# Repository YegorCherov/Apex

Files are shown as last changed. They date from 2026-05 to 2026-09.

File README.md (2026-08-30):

# Apex

Sequential 4-payload dropper for FPV drones, driven by a single servo.

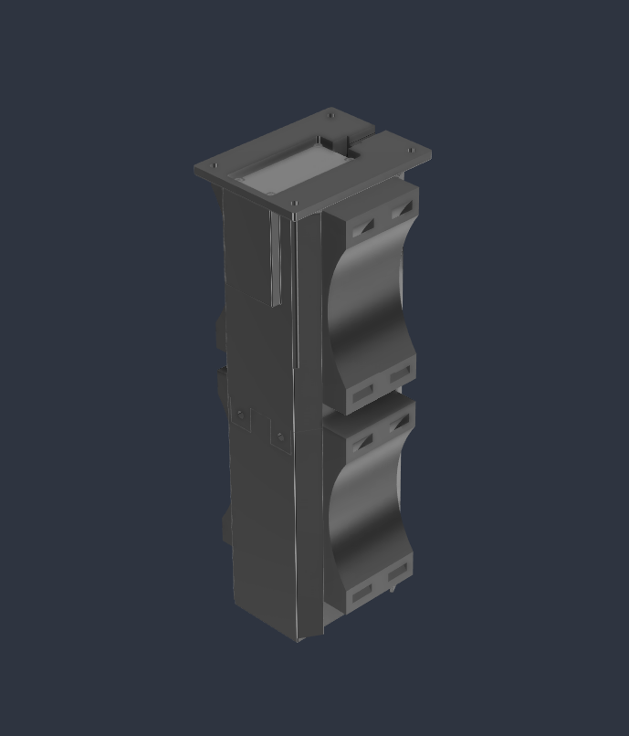
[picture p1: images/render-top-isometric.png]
Apex mounted on drone - top isometric view

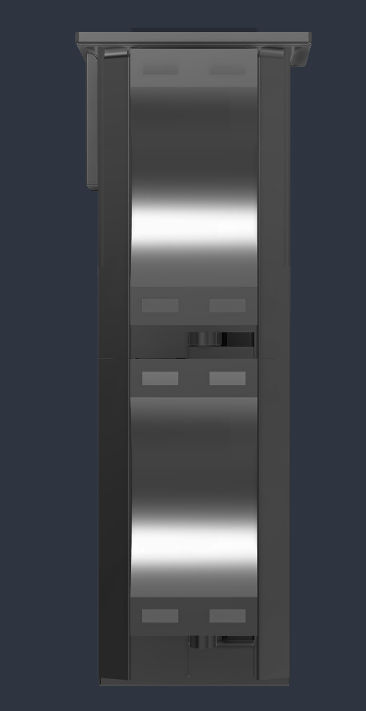
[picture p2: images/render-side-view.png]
Apex drone integration - side view with landing gear


## Overview

Apex drops up to four independent payloads at separate points in a single 180° servo sweep. There's no onboard electronics beyond the servo itself and no extra FC channels beyond the one driving it.

Payloads attach through zip ties rather than a fixed-geometry bay, so the same hardware handles a wide range of payload shapes and sizes without reprinting.

**Demos**

https://github.com/user-attachments/assets/e3766b08-4272-4210-bcb9-dfcf5e273cf3

V1, SG90 servo, split arm heights.

https://github.com/user-attachments/assets/bb46a15b-bc07-45ec-ad2f-8966f5d29cbe

V2, SG90 servo, unified arm set. The current release (V3) keeps V2's geometry but replaces the servo, see [Version History](#version-history).

## Features

- 4 sequential drops from a single 180° servo sweep
- Single MG996R servo, no added FC channels
- Zip tie payload mounting, works with S and M holders (8 or 4 payload capacity respectively)
- No springs, detents, or secondary latching, the Geneva mechanism holds position on its own
- Base plate bolts to a standard 10" frame pattern, adaptable to other frames in CAD

## Why not an existing design

| Approach | Limitation |
|---|---|
| Single-payload flap/pin release | One drop per flight |
| One servo per payload | Burns FC channels, adds weight and wiring |
| Revolver-style bay | Bay radius is fixed at print time, payload size can't change without a reprint |

Apex targets all of these at once: one servo, multiple sequential drops, and payload geometry that isn't baked into the print.

## How it works

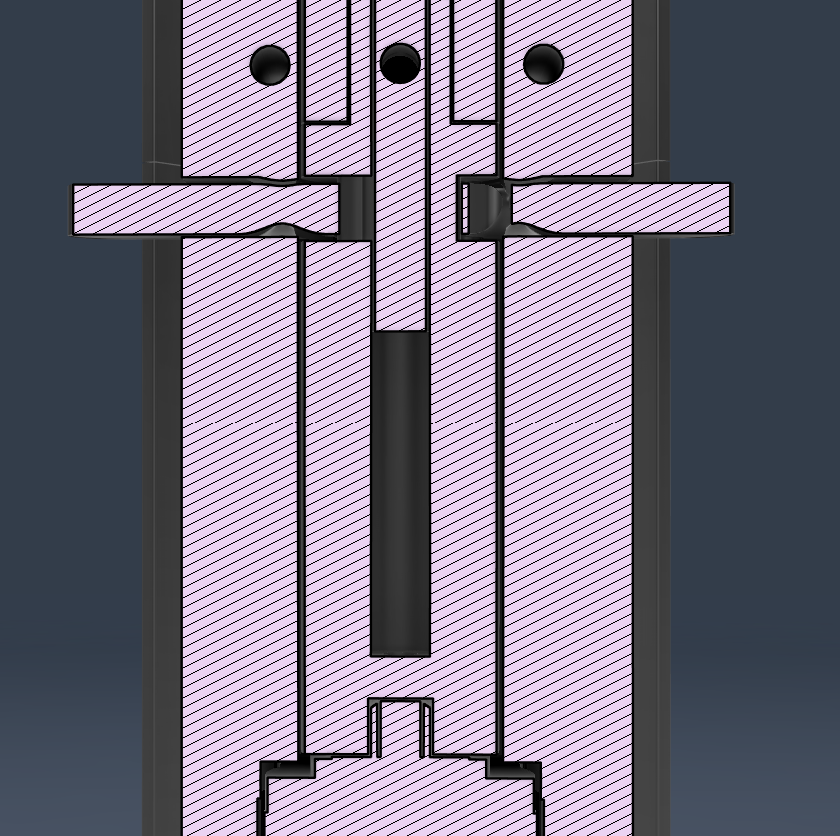
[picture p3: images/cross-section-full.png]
Cross section full view


Four Geneva mechanisms are sequenced along a single driven shaft. One continuous 180° servo rotation trips each mechanism in turn, from the bottom arm to the top.

### Geneva mechanism

A Geneva drive turns continuous rotation into indexed motion. A pin on the driver engages a slotted wheel, rotates it exactly 90°, then disengages; a locking arc on the driver holds the wheel stationary the rest of the time. That gives two things a standard gear can't: a fixed 90° throw per engagement, and a wheel that stays locked in both the open and closed position with no spring or detent needed.

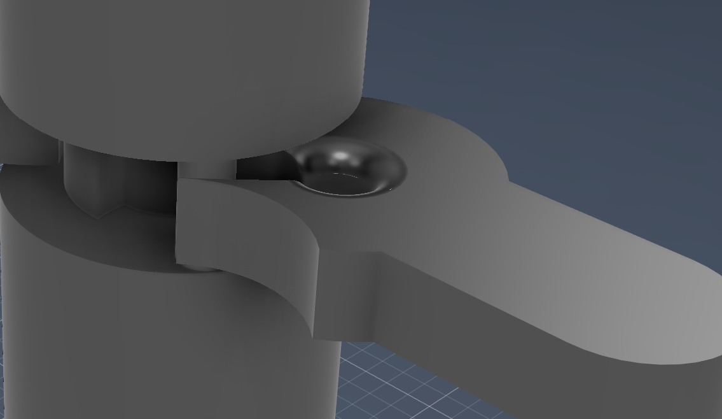
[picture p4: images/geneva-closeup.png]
Geneva engagement detail


### Drop sequence

Four engagement pillars sit on the shaft, spaced 35° apart, one per arm.

| Shaft rotation | Event |
|---|---|
| 0° | First pillar enters first Geneva slot |
| 35° | Arm 1 opens, second pillar engages |
| 70° | Arm 2 opens, third pillar engages |
| 105° | Arm 3 opens, fourth pillar engages |
| 140° | Arm 4 opens |
| 180° | Sweep complete |

The servo holds at 180° after the sweep. Nothing moves again until it's commanded back to reset.

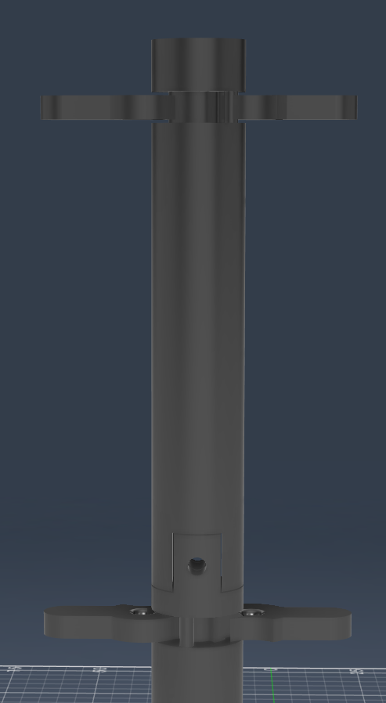
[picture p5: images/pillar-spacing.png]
Pillar spacing detail


### Arm pivot

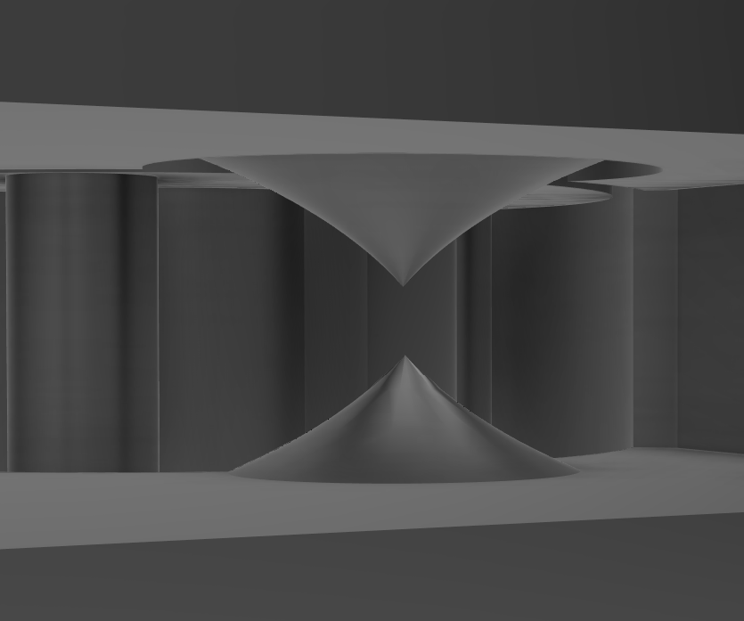
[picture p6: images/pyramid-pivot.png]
Pyramid pivot socket

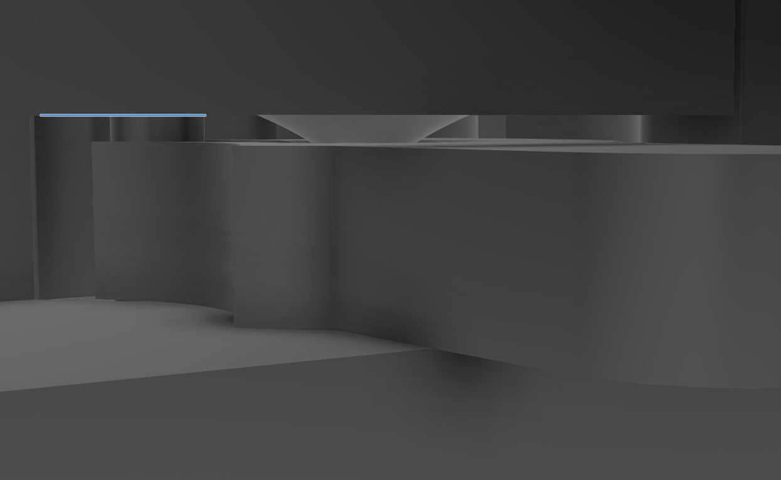
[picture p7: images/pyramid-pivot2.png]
Pyramid pivot socket


Cylindrical pins were the first approach and failed under load, the contact area in printed plastic is too small and shears. The current socket uses a pyramid profile instead: wide at the base, narrowing to a rounded tip, with the arm cradled from both above and below. Load spreads across the pyramid face rather than concentrating on a line contact, which held up substantially better in testing.

### Servo and shaft

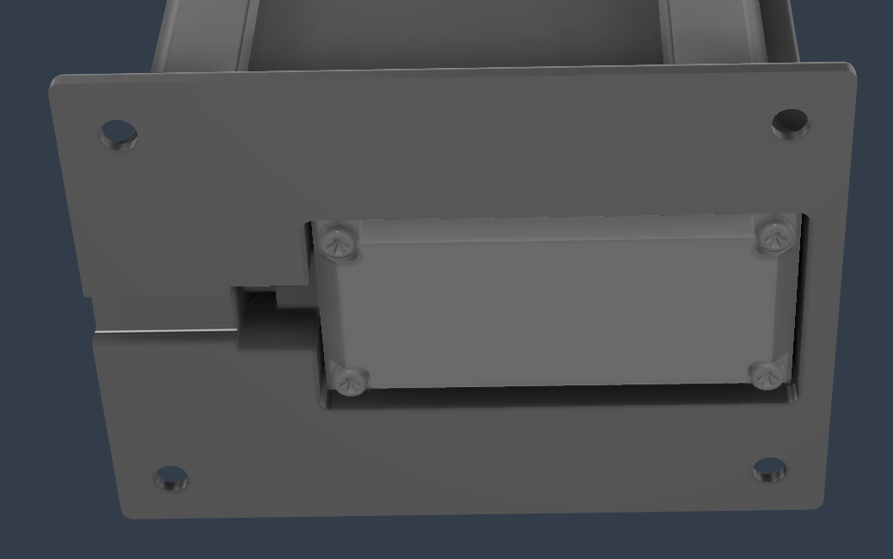
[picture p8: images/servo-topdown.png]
Servo connection top down

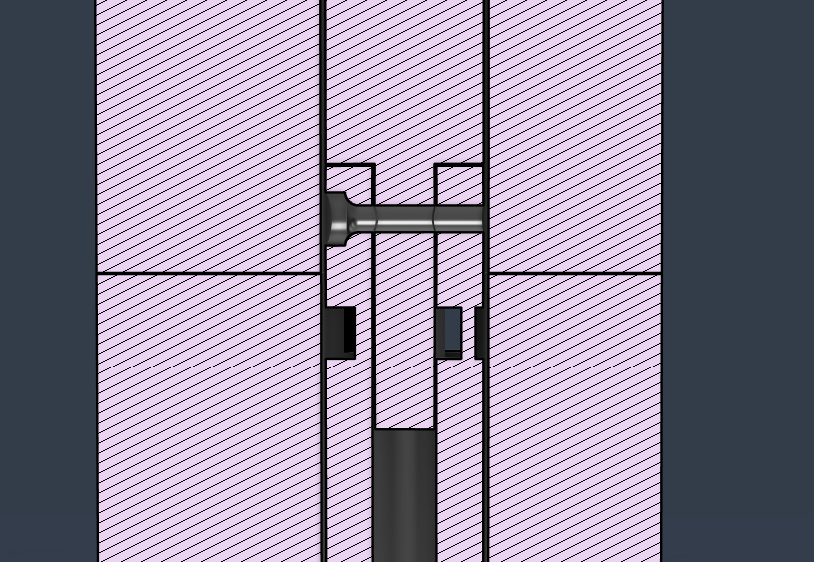
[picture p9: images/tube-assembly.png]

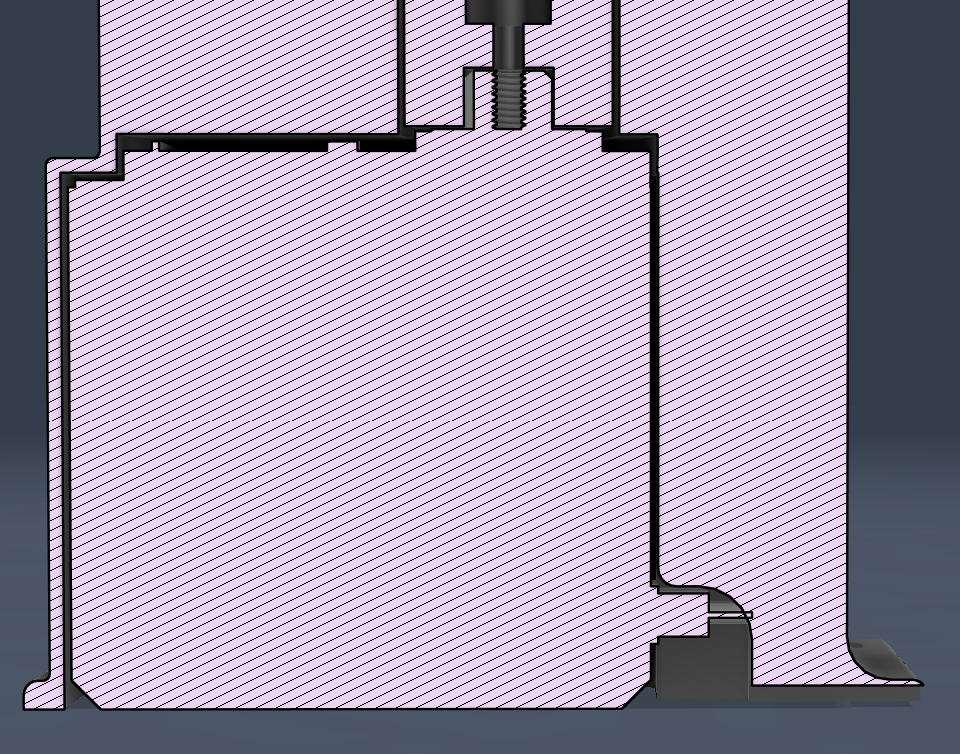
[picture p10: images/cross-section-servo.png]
Internal shaft cross section


The MG996R sits in the lower housing with its horn coupled directly to the central shaft, which runs the full height of the tube. The shaft splits into two printed parts (Tube Top, Tube Bot) that assemble around the internal structure; the four engagement pillars are molded into the shaft itself.

## Payload holders

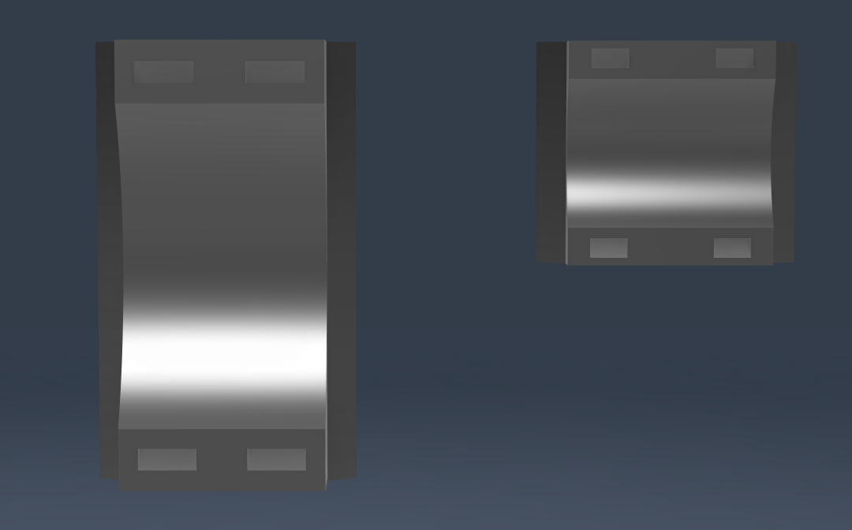
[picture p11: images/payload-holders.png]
Payload holders array


| Size | Capacity |
|---|---|
| S | 8 |
| M | 4 |

Each holder has zip tie holes for securing a payload, then slides onto an arm where it's locked in the closed position. Opening the arm 90° via the Geneva drive releases the holder along with the payload. Any payload that can be ziptied to a holder is compatible, there's no fixed bay geometry to work around.

## Specifications

| Parameter | Value |
|---|---|
| Servo | MG996R |
| Operating voltage | 6V, via step-down from drone battery |
| Servo travel | 180° |
| Payload capacity | 4 (M holders) or 8 (S holders) |
| Payload attachment | Zip ties |
| Drive mechanism | 4x Geneva mechanism, single shaft |
| Pillar spacing | ~35° |
| Frame compatibility | 10" bolt pattern (adaptable in CAD) |

## Bill of materials

| Part | Qty | Notes |
|---|---|---|
| MG996R servo | 1 | Or equivalent torque class |
| Step-down converter | 1 | Set to 6V output |
| M2 / M3 / M4 screws | assorted | Servo mount and housing |
| Zip ties | 8-16 per mission | Payload attachment |
| PLA or PETG filament | ~65g | PETG recommended |

## Printing

| Setting | Value |
|---|---|
| Layer height | 0.2mm |
| Infill | 40% minimum |
| Infill pattern | Gyroid or honeycomb |
| Material | PETG preferred, PLA acceptable |
| Supports | Required, arm sockets and servo bay |
| Perimeters | 4 minimum |

The pyramid pivot sockets carry the tightest tolerances in the print. If your printer runs loose, scale the shaft pillars down 1-2% before slicing rather than sanding fit after the fact.

## Assembly

1. Print all parts and clean support material from the pivot sockets and Geneva slots.
2. Seat the MG996R in the lower servo bay.
3. Fit the bottom tube, checking orientation, and secure it to the servo horn with the included screw.
4. Slide the top tube onto the bottom tube and lock with an M3 screw.
5. Fit latch arms 1 and 2 into their sockets.
6. Attach Shell Addition to Shell Main (four M3 screws, both directions); this clamps arms 1 and 2 in place.
7. Fit latch arms 3 and 4 into the remaining sockets.
8. Attach the lid to Shell Addition with four M3 screws to clamp arms 3 and 4.
9. Bolt the base plate to the drone frame (4 mounting holes).
10. Wire per the section below.
11. Bench test a full 180° sweep before flying.
12. Zip tie payloads to holders, slide holders onto arms, and rotate arms closed.

## Wiring

1. Drone battery → step-down converter input
2. Step-down output set to 6V
3. Step-down output → MG996R power/ground
4. MG996R signal → any free servo output on the FC

Do not run the MG996R off the FC's 5V rail directly, it draws enough current under load to brown out the FC or damage the BEC.

### Transmitter setup (RadioMaster)

Map a switch or dial to the servo channel with a 5-point custom curve:

| Point | Output | Position |
|---|---|---|
| 1 | -100% | 0° (armed) |
| 2 | -50% | 35° (drop 1) |
| 3 | 0% | 70° (drop 2) |
| 4 | +50% | 105° (drop 3) |
| 5 | +100% | 140-180° (drop 4) |

Step through points sequentially in flight to release payloads in order.

## Mounting and Drone Integration

Base plate bolt pattern matches a Mark4 V2 10" frame. For other frames, edit the base plate in CAD; the housing itself doesn't need to change.

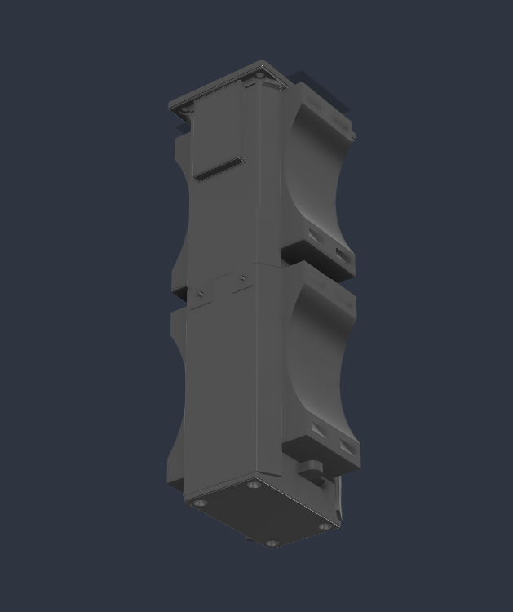
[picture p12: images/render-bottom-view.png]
Apex mounted on drone - bottom view

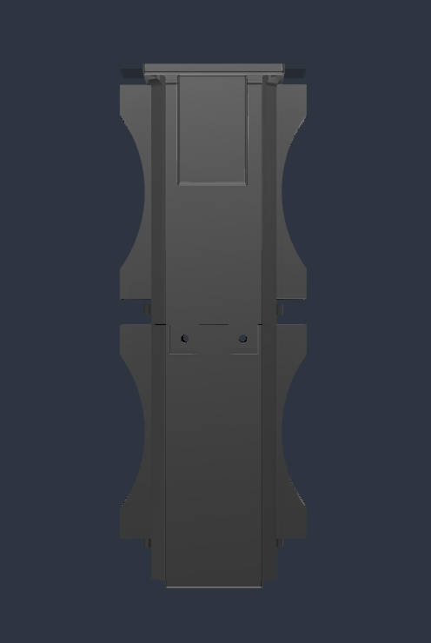
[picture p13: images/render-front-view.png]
Apex mounted on drone - front view


## Version history

| Version | Servo | Change |
|---|---|---|
| V1 | SG90 | First working proof of the Geneva sequencing concept. Split arm geometry (two heights) since all four pillars couldn't sit level. SG90 stalled under load regardless of print tolerance, insufficient torque for a 4-stage sequence. |
| V2 | SG90 | Reworked pillar spacing and shaft diameter so all four pillars sit at one height, enabling a single unified arm set. Kept the SG90 deliberately to isolate the geometry fix; it still stalled, confirming the servo was the bottleneck, not the mechanism. |
| V3 | MG996R | Scaled the whole design up 20% to fit the MG996R, which also improved wall thickness and Geneva slot clearance. No stalls at 6V under payload load. Current release. |

## Known limitations

- Base plate ships sized for a 10" frame; other frame sizes need a CAD edit before printing.
- SG90 is not viable at any print tolerance, this isn't a fit-and-finish issue.
- Payload weight hasn't been formally load-tested past normal FPV payload range; heavy single payloads (500g+) are untested.

## Repository structure

```
3d print/       V3 STL files, ready to print
cad/
  v1/           V1 source
  v2/           V2 source
  v3-final/     V3 source (current)
images/
```

## License

MIT. Use, modify, and redistribute freely. If you improve on it, a pull request or a link back is appreciated.

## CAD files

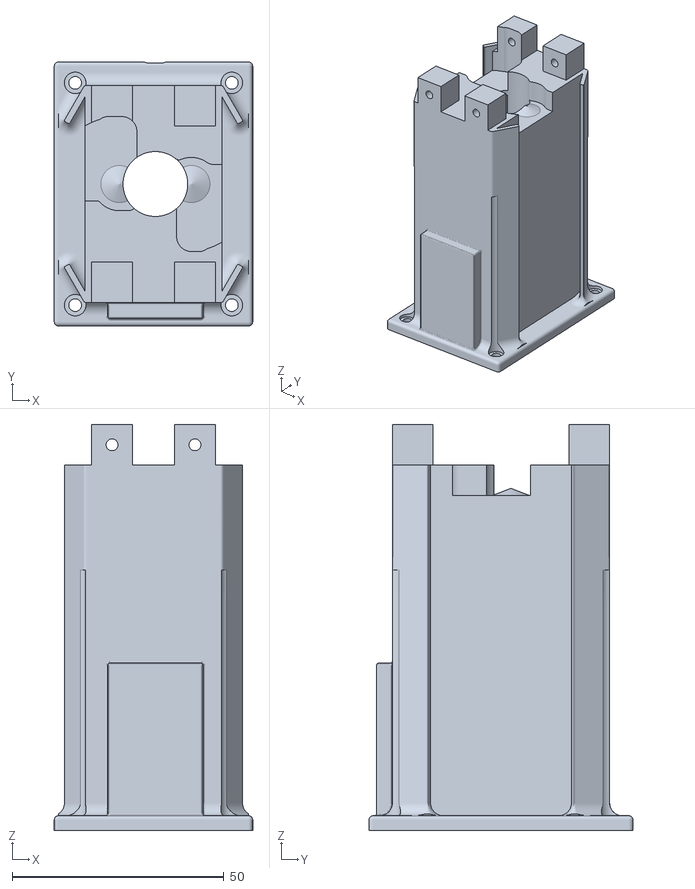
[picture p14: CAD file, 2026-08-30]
3d print/Shell Main.stl
46.9 x 62.4 x 95.9

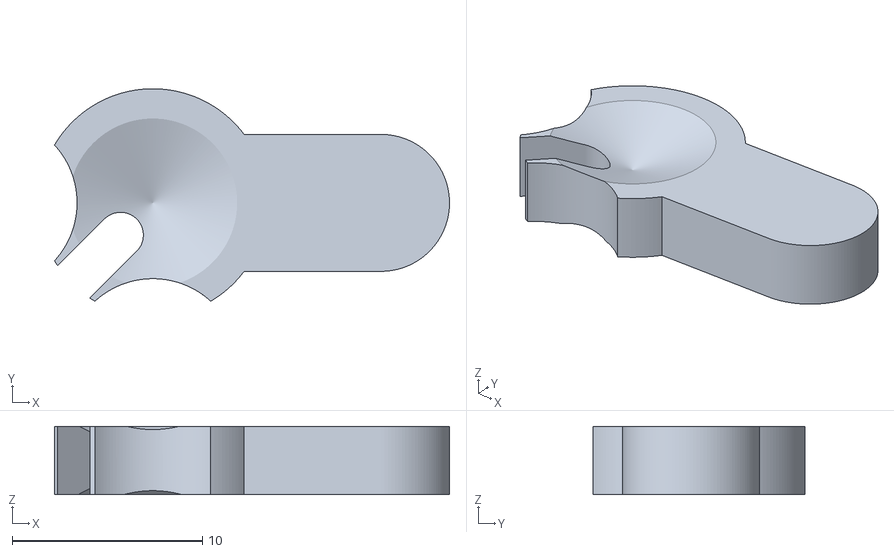
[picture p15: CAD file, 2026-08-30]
3d print/Latch 1.stl
20.8 x 11.2 x 3.60

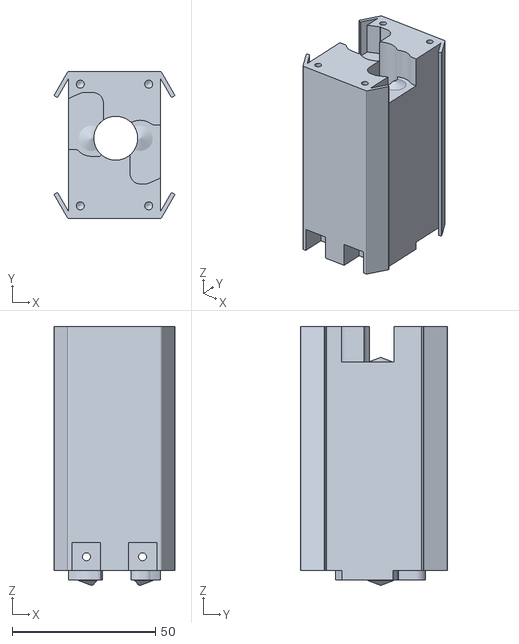
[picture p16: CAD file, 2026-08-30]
3d print/Shell Addition.stl
42.1 x 51.4 x 90.4

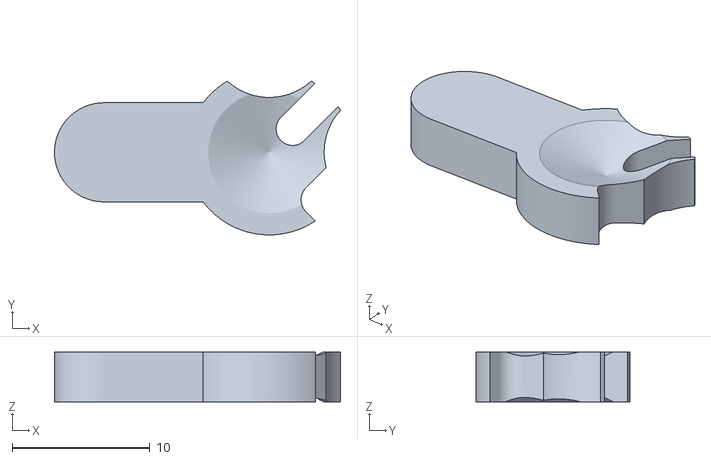
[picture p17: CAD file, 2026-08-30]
3d print/Latch 3.stl
20.8 x 11.2 x 3.60

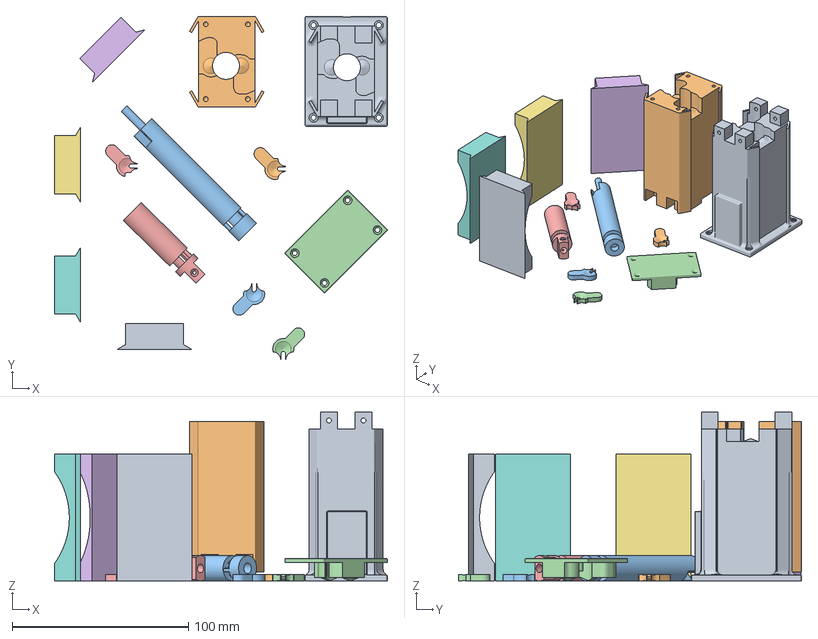
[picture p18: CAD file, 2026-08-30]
3d print/dropper_all_parts.3mf
189.0 x 194.7 x 95.9 mm
Shell Main.stl
Shell Addition.stl
Tube Top.stl
Lid.stl
Tube Bot.stl
Payload Body Medium.stl x 4
Latch 1.stl
Latch 2.stl
Latch 4.stl
Latch 3.stl

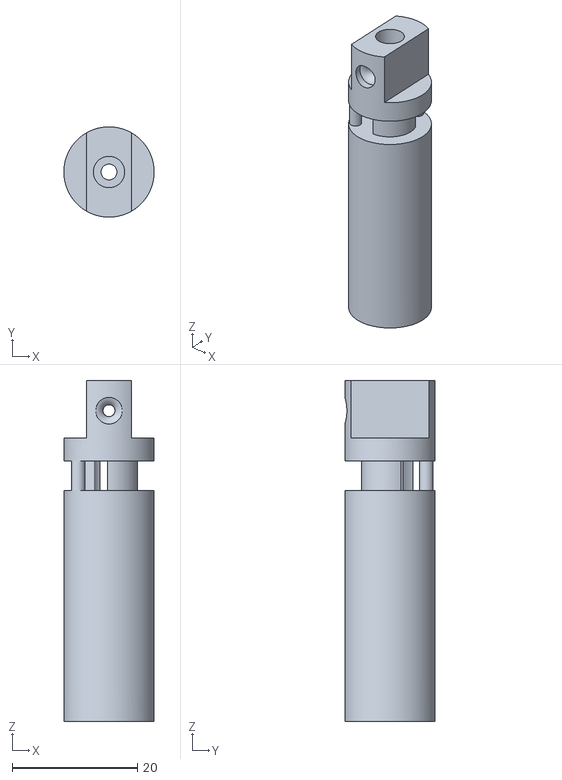
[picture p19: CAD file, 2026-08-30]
3d print/Tube Bot.stl
14.4 x 14.4 x 54.3

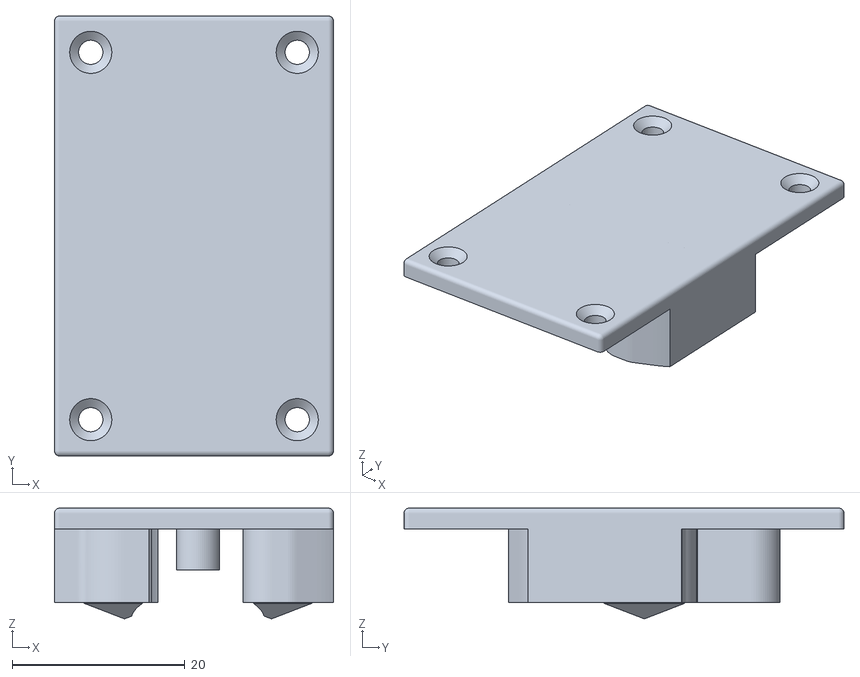
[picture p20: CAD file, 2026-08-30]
3d print/Lid.stl
32.3 x 50.9 x 12.8

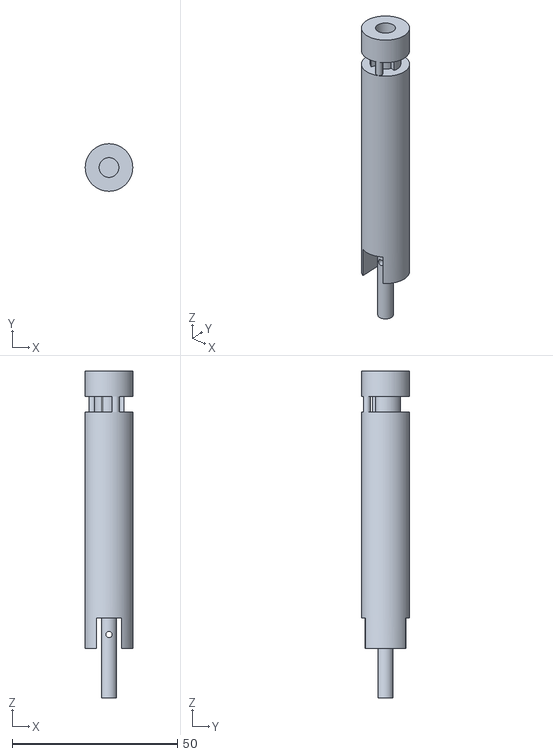
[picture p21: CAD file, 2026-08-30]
3d print/Tube Top.stl
14.4 x 14.4 x 99.0

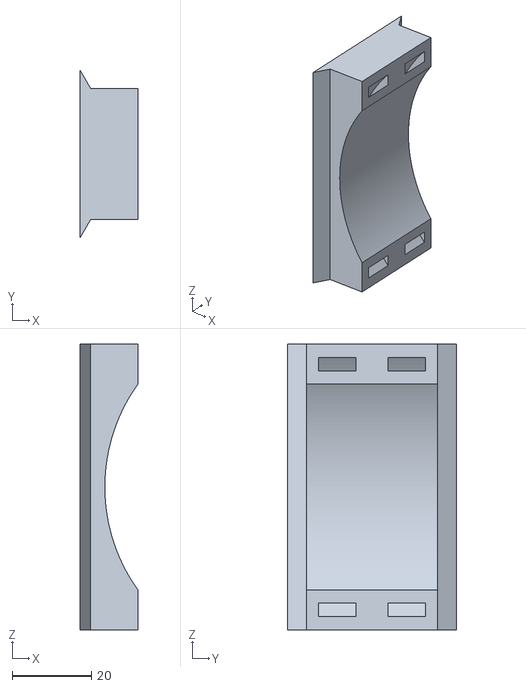
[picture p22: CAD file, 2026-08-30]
3d print/Payload Body Medium.stl
14.7 x 42.5 x 72.0

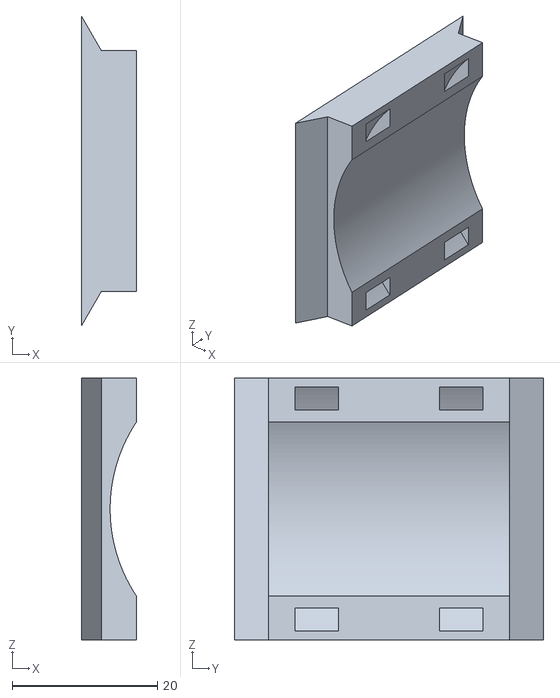
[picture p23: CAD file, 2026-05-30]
3d print/Payload Body.stl
7.52 x 42.5 x 36.0

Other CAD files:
cad/v1/fpv dropper V1.f3z
cad/v2/fpv dropper V2.f3z
cad/v3/fpv dropper V3.f3z
cad/v4-final/fpv dropper V4.f3z

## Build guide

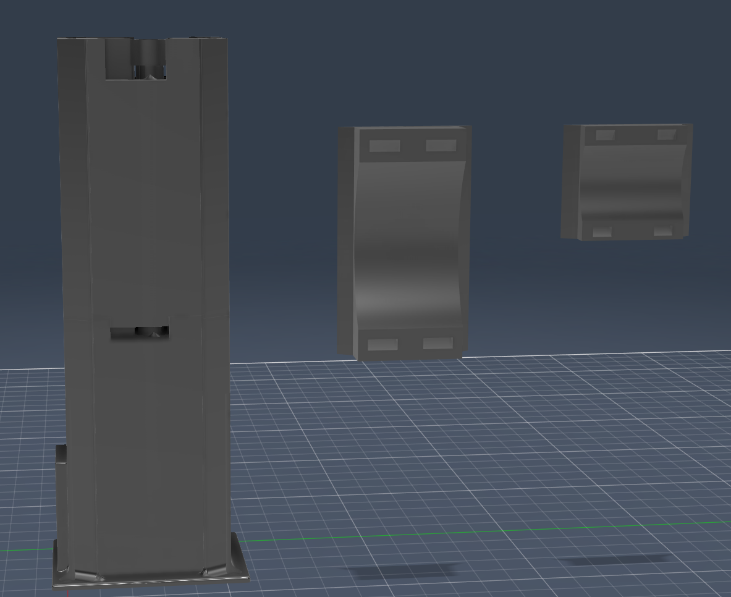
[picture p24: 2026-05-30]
images/assembly-overview.png

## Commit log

2026-05-30 Add Apex FPV dropper initial release: CAD files, README, wiring guide and mechanism documentation
    [Latch 1.stl, Latch 2.stl, Latch 3.stl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]
2026-05-30 new v1
    [fpv dropper V1.f3z]
2026-07-31 V3 Final
    [fpv dropper V3.f3z]
2026-08-30 Add new folder and files
    [Latch 1.stl, Latch 2.stl, Latch 3.stl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]
